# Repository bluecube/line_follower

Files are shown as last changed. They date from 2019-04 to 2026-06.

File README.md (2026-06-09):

Line follower v2
================

This is a robot I made to tinker with and to compete in the [Robotic Day](https://roboticday.org/) competition. (Actually the original goal was Robotic Day 2016, but stuff got delayed :) )

The design is an attempt to make a line follower with minimum effort on the hardware side and maximum versatility on the software side.

The robot body consists of a 8cm x 10cm double sided PCB, two geared N20 DC encoder motors with Pololu wheels and magnetic encoders and a few 3D printed bits.
The most important electronic components are ESP32 development board for computing power and line sensor inspired by [Ondřej Staněk's PocketBot](http://www.ostan.cz/pocketBot/), as a bonus the robot also carries an IR range sensor and MPU 6050 breakout board (accelerometer and gyro).

This repository should contain everything necessary to build and run the robot in the competition.
Let me know if you decide to build it!

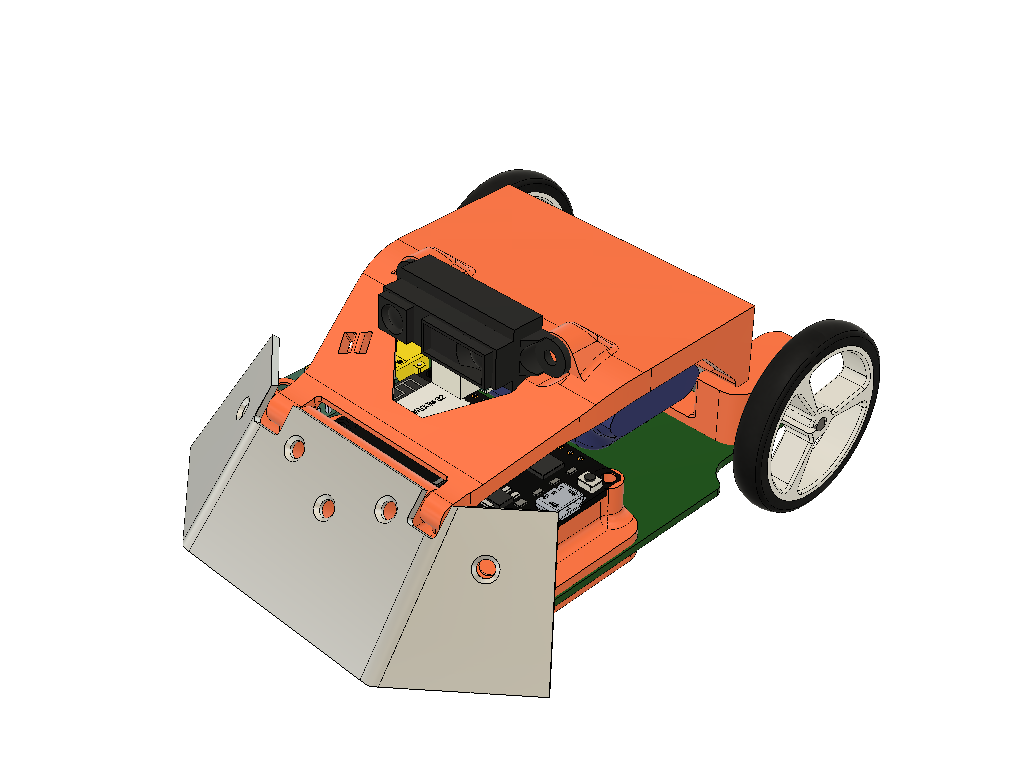
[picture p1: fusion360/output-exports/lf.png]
Render of the robot


This is a v2, you can also check out the [v1](https://github.com/bluecube/line_follower/tree/v1/).

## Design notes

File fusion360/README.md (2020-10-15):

The robot has a PCB base with 3D printed parts bolted to it.

All 3D printed parts should be printable without supports, although
some parts are a little more difficult:

- Deck is printed standing on the (only) flat face. It is tall and overhanging, good cooling is necesary. Orient the longer side of the base along the movement of the Y axis.
- Motor bracket has long bridges supported only by thin columns.

The mechanical design was done in a little roundabout way:

1. 2D sketches of the PCB were done in F360 (`board-base-sketches.f3d`)
2. The base sketches were exported to DXF files in the `pcb-exports/` directory.
3. PCB was designed based on these exported DXF files (`../kicad/`)
4. The PCB design was then exported as STEP, imported into F360 and used as a base for most of the 3D modelling (`lf.f3z`).
5. Various outputs were then exported from F360 for fabrication (`output-exports/`)

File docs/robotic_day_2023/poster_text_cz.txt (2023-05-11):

LF2
- Cíl: jednoduchý hardware, maximální flexibilita
- Ve vývoji již několik let, poprvé se blíží dokončení
- Předchozí robot Procrastinator 9000
   - Kvalifikoval se, ale nezávodil na Robotickém Dni 2019
   - Efekt druhého systému je skutečný!

Mechanika
- Základ je deska plošných spojů
- 3D tištěné díly z PETG
- Otevírací horní poklop slouží zároveň jako tlačítko zastavení
- Hliníkový pluh, spíše jen pro dekoraci
- Motory N20 s převodovkami a enkodéry
- 40mm kolečka

Elektronika a senzory
- ESP32
- Vlastní čárový senzor
   - Střídavě červené LED a fototranzistory, 10 měřených bodů
- A4950 H-můstky
- MPU6050 šestiosé IMU
- Laserový snímač vzdálenosti

Software
- PlatformIO pro správu toolchainu a závislostí
- C++17
- Používá ESP-IDF, ne Arduino
- Vrstva abstrakce hardwaru
   - Skryje přístup k ESP-IDF, hardware robota reprezentovaný jako singleton třída
- Hierarchický stavový automat pro programování chování

3D modely, elektronika, kód a dokumentace jsou k dispozici na https://github.com/bluecube/line_follower

Zeptejte se mě více o projektu: blue.cube@seznam.cz

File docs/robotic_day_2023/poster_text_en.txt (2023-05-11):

LF2
- Design goal: simple hardware, maximum flexibility
- In development for several years now, first time close to being finished
- Preceeded by Procrastinator 9000
  - Qualified, but didn't race in Robotic Day 2019
  - Second system effect is real!

Mechanical
- PCB base
- 3D printed PETG parts
- Opening top hatch doubles as a stop button
- Alluminium armor/plow, mostly decorative
- N20 gear motors with encoders
- 40mm wheels

Electronics and sensors
- ESP32
- Custom line sensor
  - Alternating red LEDs and phototransistors, 10 measured points
- A4950 H-bridges
- MPU6050 six axis IMU
- Laser distance sensor

Software
- PlatformIO for toolchain and dependency management
- C++17
- Using ESP-IDF, not Arduino
- Hardware abstraction layer
  - Hides ESP-IDF access, robot hardware represented as a singleton class
- Hierarchical state machine for programming behaviors

3D and electronics design, code and documentation are available at https://github.com/bluecube/line_follower

Ask me more about the project: blue.cube@seznam.cz

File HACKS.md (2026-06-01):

# HACKS.md

Known workarounds for hardware and driver issues.

## esp-hal `Adc::new` ignores attenuation for ADC2

`Adc::new` hardcodes `ADC1::set_attenuation` even when called with an `ADC2` peripheral, so ADC2
channels are silently left at the register default instead of the requested attenuation.

Workaround in `lf-hal/src/line_sensor.rs`: after both `Adc` instances drop, manually call
`ADC2::set_attenuation` for every ADC2 channel.

TODO: We have since upgraded esp-hal, maybe it's not necessary any more.

## BLE PHY ISR corrupts ADC2 reads

The BLE stack uses ADC2 for TX power detection. After each measurement the PHY ISR leaves
`SAR2_PWDET_FORCE=1` in `SAR_READ_CTRL2`, routing the ADC2 input mux to the internal PWDET
signal instead of the GPIO pin. Reading ADC2 without clearing this bit returns garbage.

Workaround in `lf-hal/src/line_sensor.rs`: `start_adc2()` clears `sar2_pwdet_force` before every
conversion, and every ADC2 read is wrapped in a `critical_section` to prevent the PHY ISR from
re-setting the bit between the clear and the read.

Note: the next hardware revision should route all phototransistor ADC lines to ADC1, eliminating
both workarounds.

## GPIO 12 strapping pin conflict with distance sensor

The IR distance sensor is connected to GPIO 12, which is the MTDI strapping pin on the ESP32. At
boot, the ESP32 samples this pin to determine the VDD_SDIO regulator voltage: HIGH selects 1.8V,
LOW selects 3.3V. With the sensor connected the pin was driven HIGH, causing the chip to boot with
VDD_SDIO at 1.8V and preventing correct operation and flashing.

Fix: permanently burned the VDD_SDIO efuse to force 3.3V, disabling GPIO 12's role as a strapping
pin. This is irreversible. Command used (via PlatformIO's bundled esptool):

```
pip install ecdsa reedsolo bitstring
pio pkg exec --package "platformio/tool-esptoolpy" -- espefuse.py --port /dev/ttyUSB1 set_flash_voltage 3.3V
```

See also: `docs/instructions.md`.

## Button noise

Deck button seems to have problems with EMI when mtors are spinning at full.
So far this only appears in motor_test.rs.
Either we will require multiple samples from the button to agree, or an electrical solution
(caps on the motors, caps on the button). Perhaps both.

TODO: Verify and implement the fixes

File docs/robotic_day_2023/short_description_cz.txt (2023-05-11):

LF2 je robot navržený s důrazem na jednoduchou hardwarovou konstrukci a co největší flexibilitu.
Jeho vývoj probíhá již několik let, přičemž největší pokrok obvykle dosahuje
noc před (většinou neůspěšnou) registrací na Robotický Den.
Robotovi LF2 předcházel robot Procrastinator 9000 navržený s podobným přístupem.
(Nejen) kvůli tomu trpí LF2 silným efektem druhého systému ("nevadí že to bude mohem víc práce, radši to udělám P O Ř Á D N Ě").

Základem konstrukce je deska plošných spojů, na kterou jsou přišroubované díly 3D tištěné z PETG a hliníková radlice (spíš designový než funkční prvek).
Pohyb robota zajišťují dva motory N20 s převodovkou a kvadraturním enkodérem a 40mm Pololu kolečka.
Pro sledování čáry robot používá snímač složený ze šesti červených LED a pěti
fototranzistorů, dohromady tak umožňuje měřit odrazivost podložky na deseti pozicích (mezi dvojicemi LED a fototranzistorů).
Modul s ESP32 poskytuje naprosto nadbytečné množství výpočetního výkonu a v rezervě je ještě šestiosé IMU MPU6050 a laserový senzorem vzdálenosti.

Software robota je napsaný v jazyce C++17 a pro přístup k periferiím využívá knihovnu ESP-IDF (žádné Arduino!).
Software definuje vrstvu pro abstrakci hardwaru (HAL), která obaluje všechny přístupy k ESP-IDF, čísla pinů a podobné do jedné třídy pro snazší testování a případnou simulaci.
Chování robota při soutěži řídí jedoduchý stavový automat.
Pro správu překladače, závislostí a dalších součástí je použito prostředí Platformio (https://platformio.org).

Veškeré 3D modely, kód a dokumentace k robotu LF2 je k dispozici na GitHubu na adrese https://github.com/bluecube/line_follower.

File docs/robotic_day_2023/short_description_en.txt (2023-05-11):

LF2 is a robot designed with an emphasis on simple hardware construction and maximum flexibility.
Its development has been going on for several years, and it usually makes the most progress
the night before the (usually unsuccessful) registration for Robotic Day.
The LF2 robot was preceded by the Procrastinator 9000 robot designed with a similar approach.
(Not only) because of this, LF2 suffers from a strong second system effect ("it doesn't matter that it will be more work for me, I'd rather do it P R O P E R L Y").

The basis of the structure is a printed circuit board, on which parts 3D printed out of PETG and an aluminum armor/plow blade (more of a design element than a functional element) are screwed.
The movement of the robot is taken care of by two N20 gear motors with quadrature encoders and 40mm Pololu wheels.
To track the line, the robot uses a sensor composed of six red LEDs and five phototransistors, together this allows measuring the reflectivity of the surface at ten positions (between pairs of LEDs and phototransistors).
The module with ESP32 provides a completely unnecessary amount of computing power and there is a six axis IMU MPU6050 and a laser distance sensor in reserve.

The robot software is written using C++17 and uses the ESP-IDF library to access peripherals (no Arduino!).
The software defines a hardware abstraction layer (HAL) that wraps all ESP-IDF accesses, pin numbers, and the like into a single class for easier testing and eventual simulation.
The behavior of the robot during the competition is controlled by a simple state machine.
Platformio environment (https://platformio.org) is used to manage the compiler, dependencies and other components.

All 3D models, code and documentation for the LF2 bot is available on GitHub at https://github.com/bluecube/line_follower.

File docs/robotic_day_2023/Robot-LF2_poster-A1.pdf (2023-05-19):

# ROBOT LF2

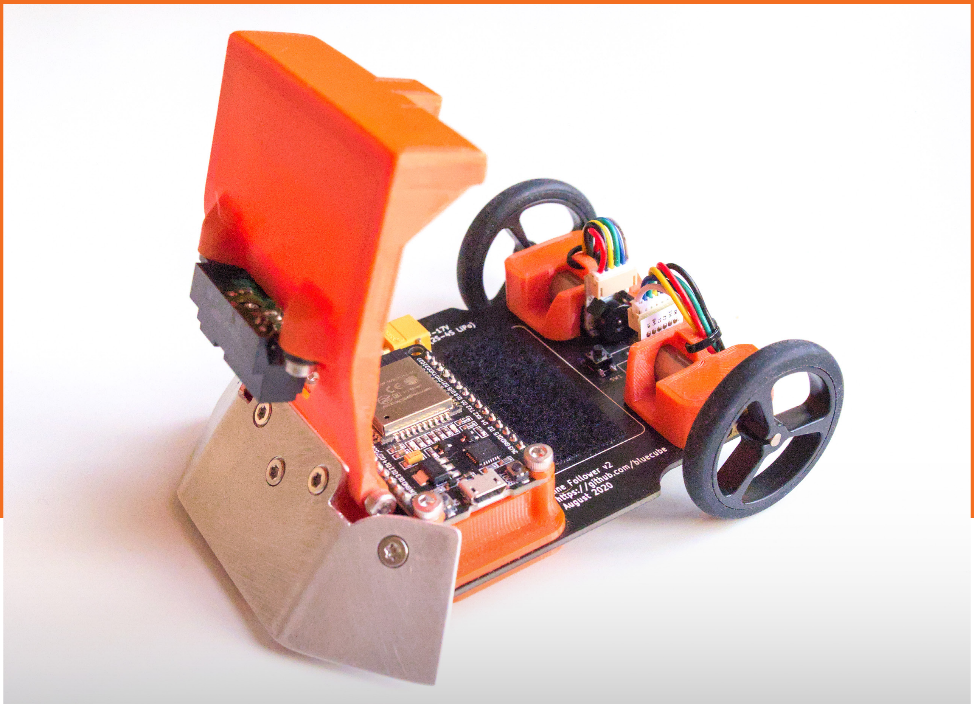
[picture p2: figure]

Mechanical
□ PCB base
□ 3D printed PETG parts
□ Opening top hatch doubles as a stop button □ Alluminium armor/plow, mostly decorative □ N20 gear motors with encoders
□ 40mm wheels
Electronics and sensors
□ ESP32
□ Custom line sensor
□ Alternating red LEDs and phototransistors, 10 measured points
□ A4950 H-bridges
□ MPU6050 six axis IMU
□ Laser distance sensor
Software
□ PlatformIO for toolchain and dependency management
□ C++17
□ Using ESP-IDF, not Arduino
□ Hardware abstraction layer
□ Hides ESP-IDF access, robot hardware represented as a singleton class
□ Hierarchical state machine for programming behaviors

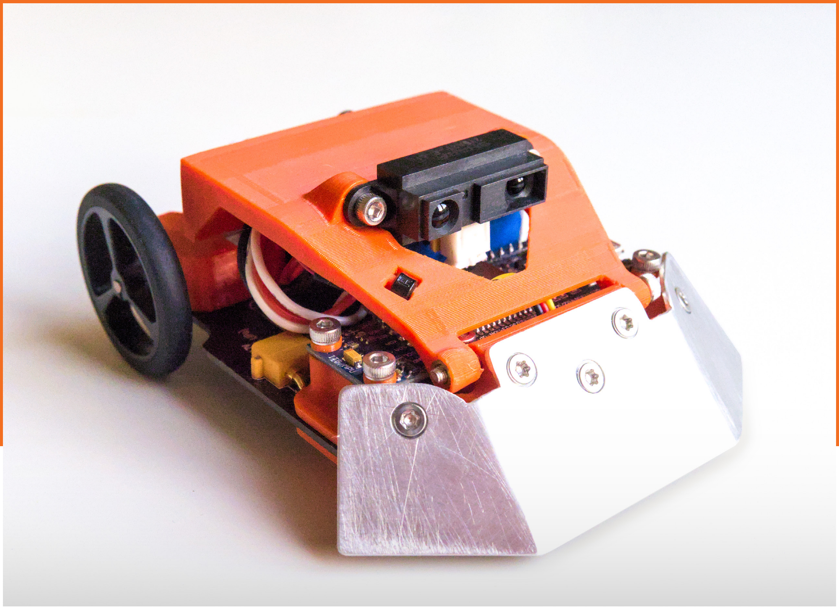
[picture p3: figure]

Mechanika
□ Základ je deska plošných spojů
□ 3D tištěné díly z PETG
□ Horní poklop slouží zároveň jako stop tlačítko □ Hliníkový pluh, spíše jen pro dekoraci
□ Motory N20 s převodovkami a enkodéry
□ 40mm kolečka
Elektronika a senzory
□ ESP32
□ Vlastní čárový senzor
□ Střídavě červené LED a fototranzistory, 10 měřených bodů
□ A4950 H-můstky
□ MPU6050 šestiosé IMU
□ Laserový snímač vzdálenosti
Software
□ PlatformIO pro správu toolchainu a závislostí □ C++17
□ Používá ESP-IDF, ne Arduino
□ Vrstva abstrakce hardwaru
□ Skryje přístup k ESP-IDF, hardware robota reprezentovaný jako singleton třída
□ Hierarchický stavový automat pro programování chování

## CÍL: jednoduchý hardware, maximální flexibilita DESIGN GOALS: simple hardware, maximum flexibility

## In development for many years now, first time close to being finished. It was preceeded by robot Procrastinator 9000, which Qualified, but didn’t race in Robotic Day 2019. Second system effect is real!

## Ve vývoji již několik let, poprvé se blíží dokončení. Předchozí robot

Procrastinator 9000 se kvalifikoval, ale nezávodil na Robotickém Dni 2019.

## Efekt druhého systému je skutečný!

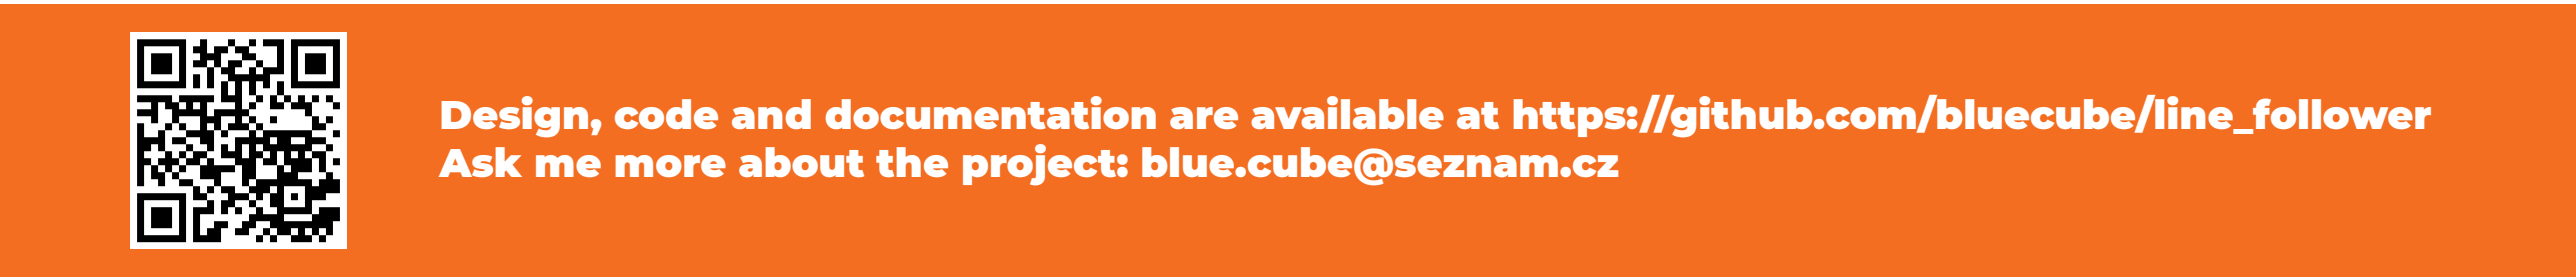
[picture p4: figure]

Design, code and documentation are available at https://github.com/bluecube/line_follower Ask me more about the project: blue.cube@seznam.cz

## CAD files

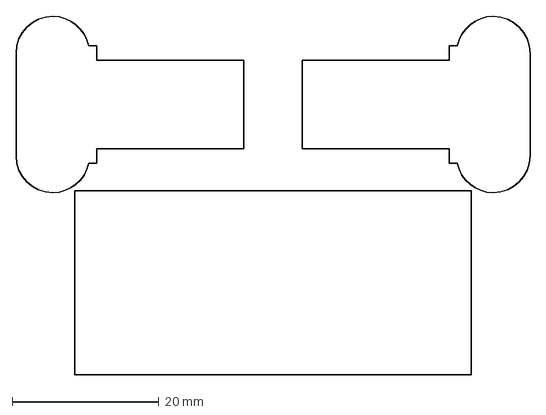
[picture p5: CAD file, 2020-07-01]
fusion360/dxf-exports/top-blockers-kicad-export.dxf
70.0 x 48.8 mm

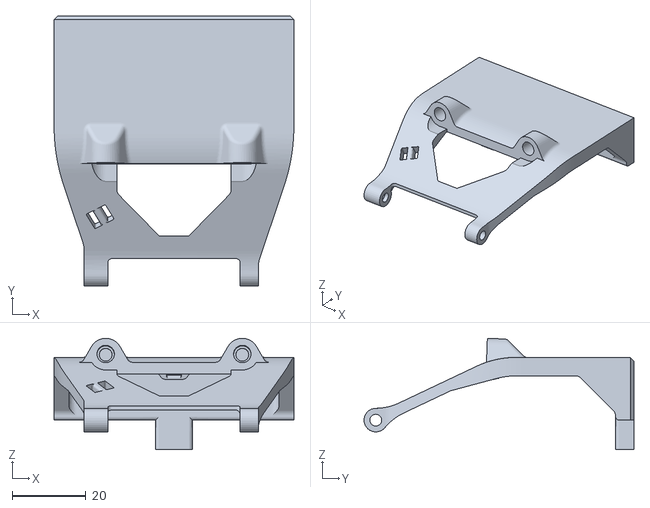
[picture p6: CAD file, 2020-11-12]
fusion360/output-exports/fdm-deck.stl
65.0 x 73.2 x 30.2

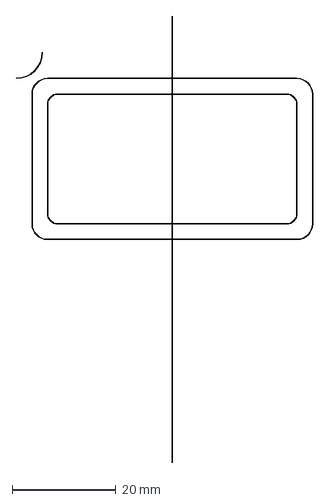
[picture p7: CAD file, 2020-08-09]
fusion360/pcb-exports/battery-outline.dxf
57.0 x 86.0 mm

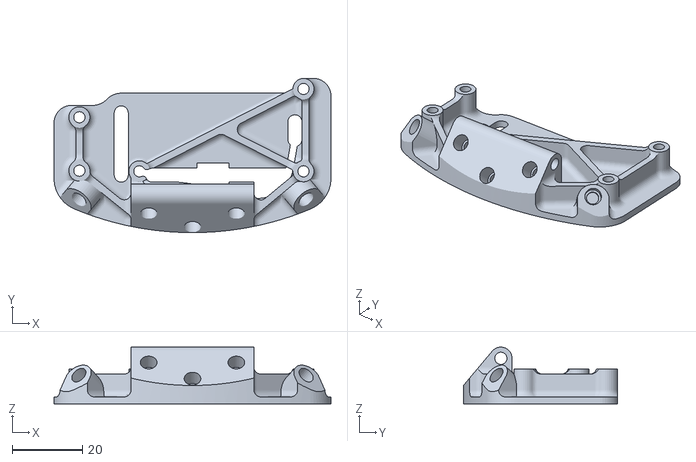
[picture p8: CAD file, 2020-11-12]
fusion360/output-exports/fdm-front_top.stl
79.0 x 44.0 x 16.2

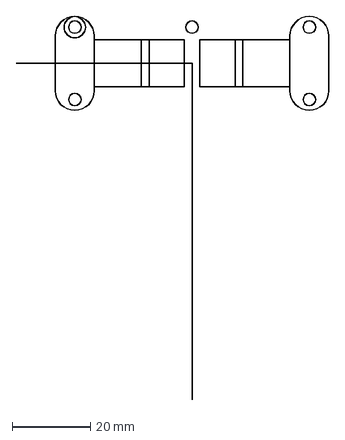
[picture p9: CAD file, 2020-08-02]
fusion360/pcb-exports/motor_mounts_outline.dxf
80.0 x 98.0 mm

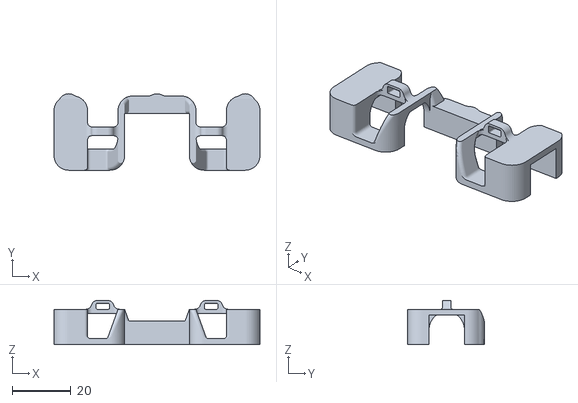
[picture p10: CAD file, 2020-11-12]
fusion360/output-exports/fdm-motor_bracket.stl
70.0 x 26.0 x 15.0

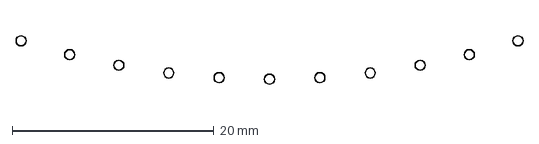
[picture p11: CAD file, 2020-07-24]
fusion360/pcb-exports/line-sensor-components.dxf
50.3 x 4.80 mm

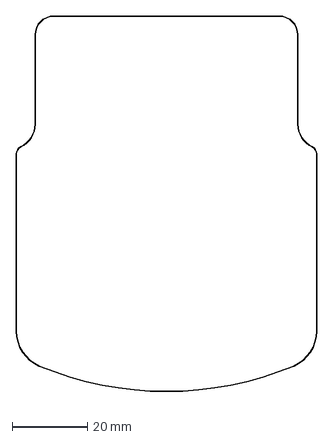
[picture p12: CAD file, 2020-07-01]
fusion360/pcb-exports/board-outline.dxf
80.0 x 102.3 mm

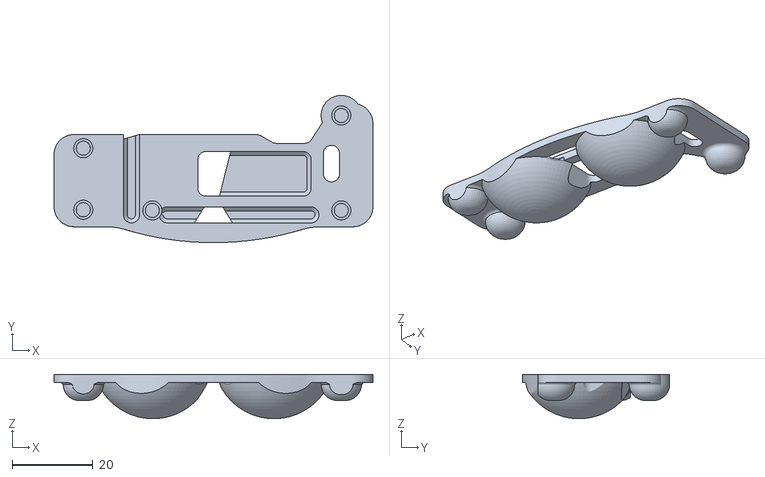
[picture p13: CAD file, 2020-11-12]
fusion360/output-exports/fdm-front_bottom.stl
79.0 x 36.5 x 11.0

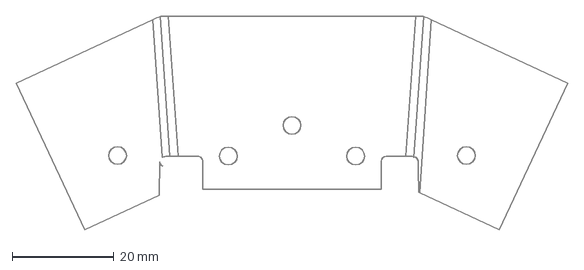
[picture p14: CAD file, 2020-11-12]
fusion360/output-exports/armor.dxf
108.1 x 42.0 mm

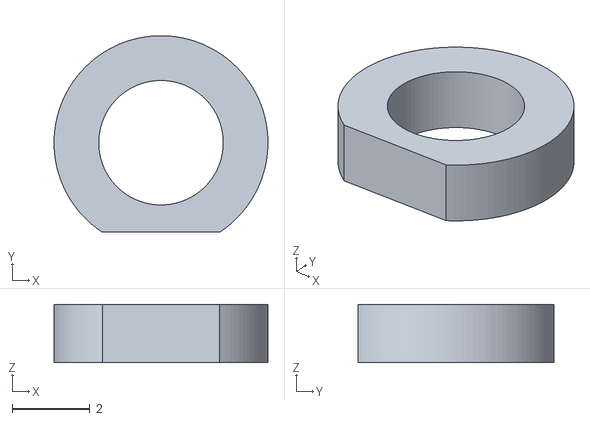
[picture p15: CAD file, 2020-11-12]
fusion360/output-exports/fdm-cut_washer.stl
5.50 x 5.05 x 1.50

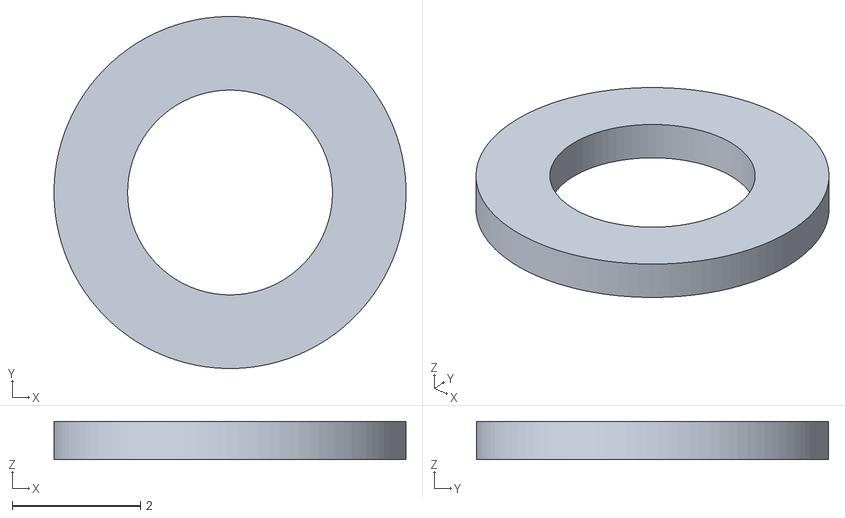
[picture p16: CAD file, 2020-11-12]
fusion360/output-exports/fdm-flat_washer.stl
5.50 x 5.50 x 0.6

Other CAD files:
solidworks/testing_map.sldprt
fusion360/board-base-sketches.f3d
fusion360/lf.f3z
fusion360/off_the_shelf/microswitch_4.5mm.f3d

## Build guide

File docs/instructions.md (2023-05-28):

# Getting the robot to work

This is mostly a random collection of things.
Not complete by any means.

## Install platformio
I couldn't get platformio to work normally, so instead I used a virtual environment:

```
python -m venv venv
. venv/bin/activate
pip install platformio
```

Then I can do
```
platformio run
```

The top level Makefile already assumes that the venv is used.

# Fixing GPIO12 conflicting with the distance sensor

By default, the board cannot be flashed correctly when the distance sensor is connected, because GPIO12 is a strapping pin (MTDI).
I followed instructions in [ESP32 docs](https://docs.espressif.com/projects/esptool/en/latest/esp32/espefuse/set-flash-voltage-cmd.html) and permantently set the VDD_SDIO regulator to 3.3V.
This disables the use of GPIO12 as a strapping pin, but it's an irreversible change.

Platformio doesn't let me directly use the `espfuse.py`, has to be accessed through a package.
In addition, there are some dependencies missing, so I installed them in the virtual env.
I also had to specify port for connecting to the ESP32.

Final commands:
```
pip install ecdsa reedsolo bitstring
pio pkg exec --package "platformio/tool-esptoolpy" -- espefuse.py --port /dev/ttyUSB1 set_flash_voltage 3.3V
```

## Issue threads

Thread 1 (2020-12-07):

GPIO12 (distance sensor) breaks flashing

bluecube, 2020-12-07:
The board cannot be flashed correctly when the distance sensor is connected, because GPIO12 is a strapping pin (MTDI).

bluecube, 2020-12-25:
Maybe swap it with SDA or SCL?

bluecube, 2023-03-03:
https://docs.espressif.com/projects/esptool/en/latest/esp32/espefuse/set-flash-voltage-cmd.html

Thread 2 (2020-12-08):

Line sensor LEDs 5 and 6 should be switched to simplify charlieplex encoding in software

bluecube, 2020-12-08:

bluecube, 2020-12-11:
... or not. The current state is simple enough, even though it is not as nice and regular as it could be

Closed 2020-12-11.

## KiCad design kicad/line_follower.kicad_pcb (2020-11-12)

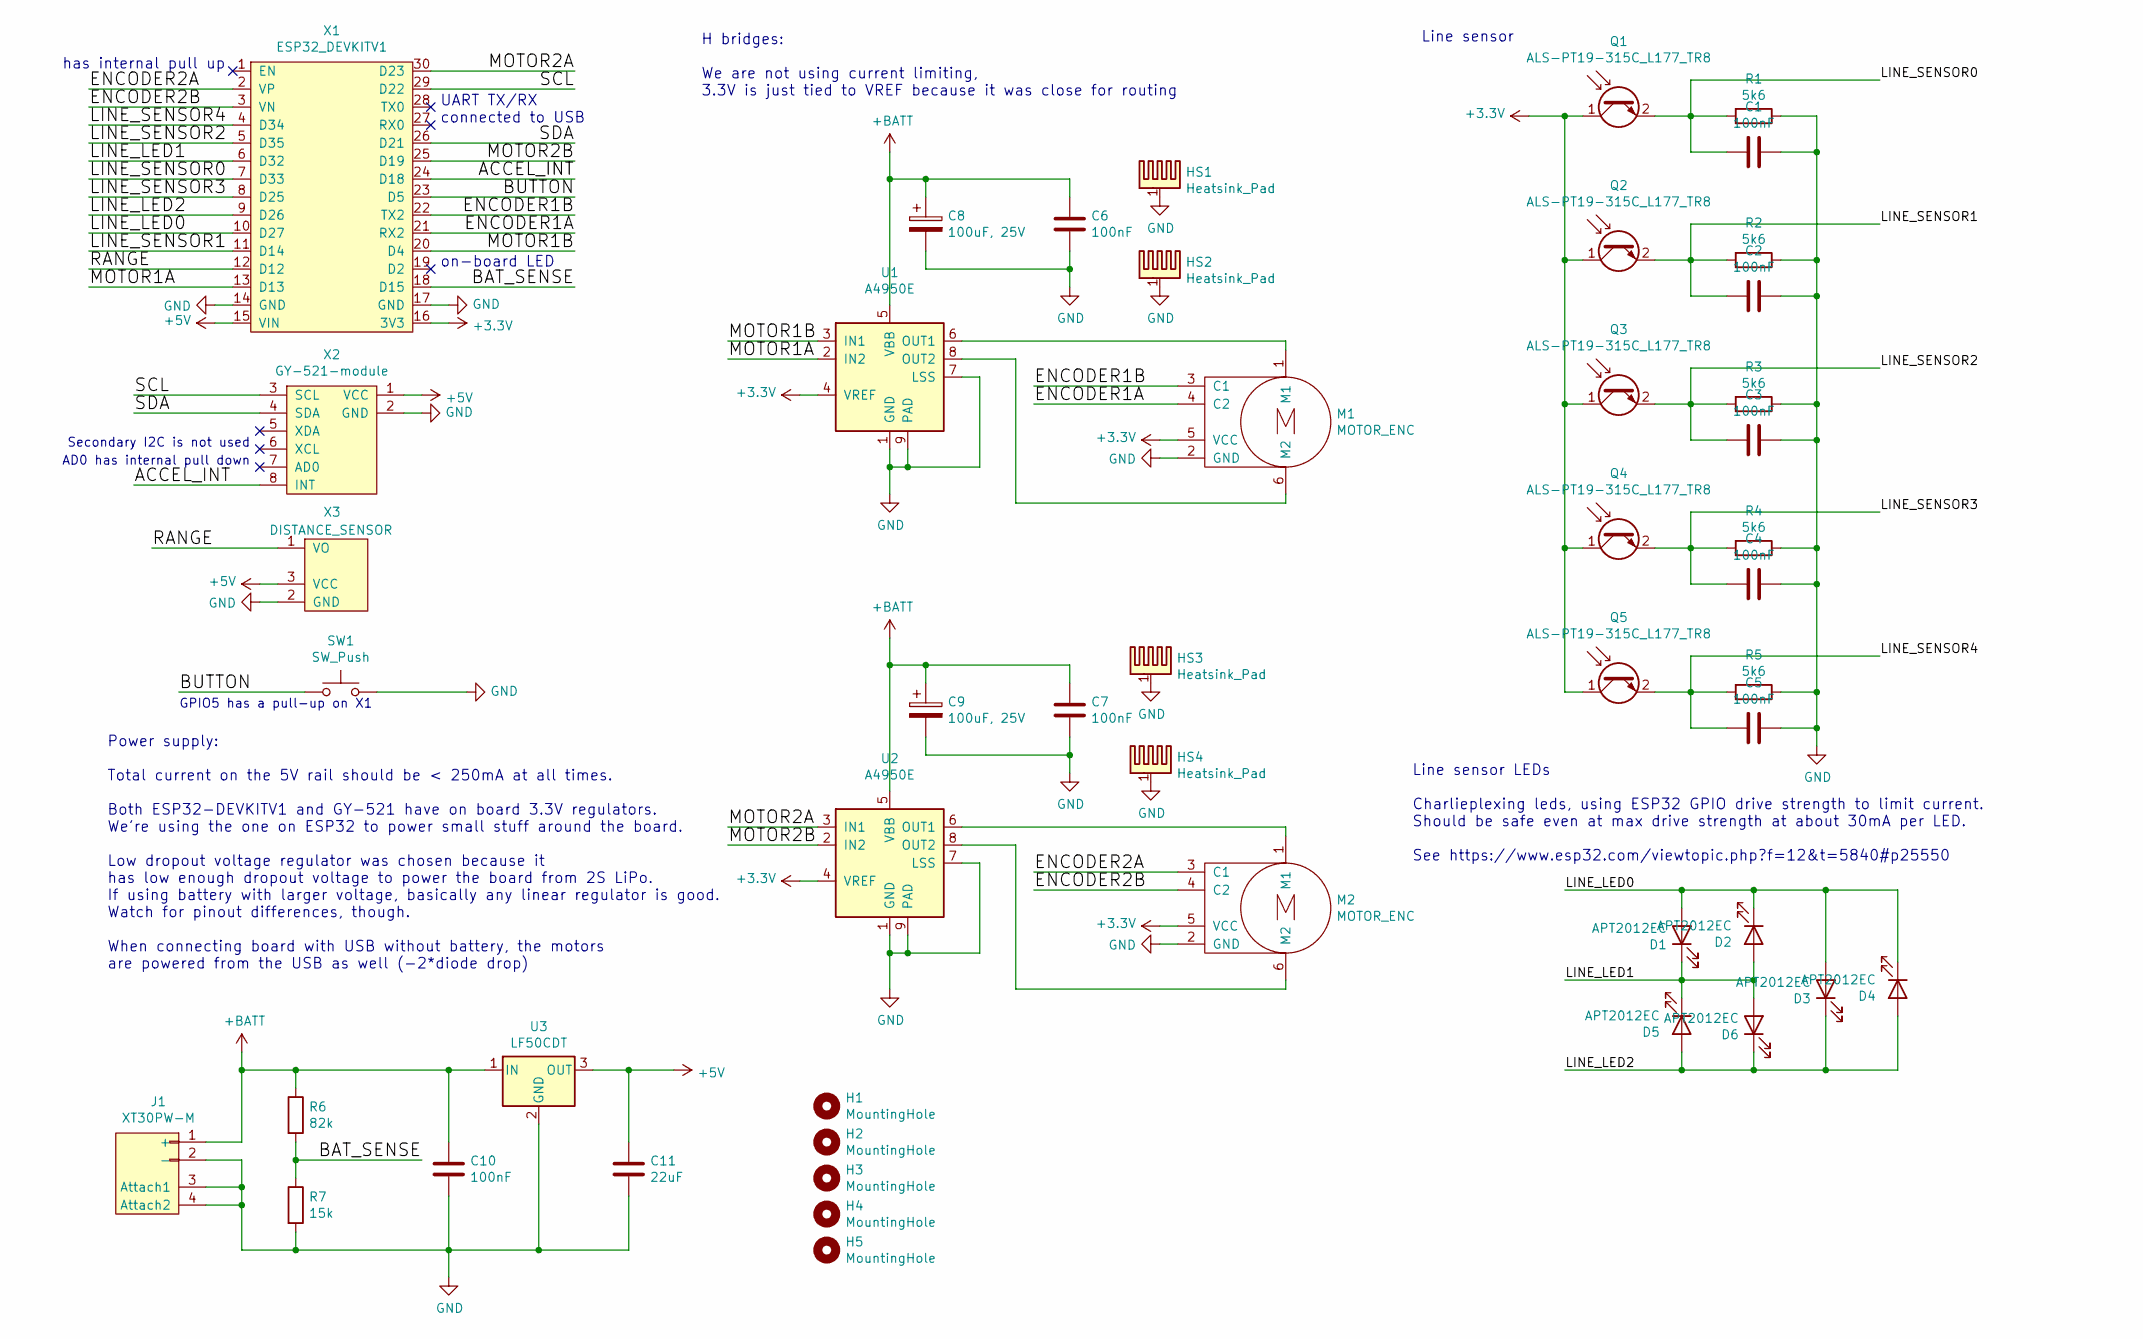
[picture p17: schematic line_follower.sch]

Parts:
C1, C2, C3, C4, C5, C6, C7, C10: 100nF; C_0805_2012Metric_Pad1.15x1.40mm_HandSolder
C8, C9: 100uF, 25V; CP_Elec_6.3x5.8
C11: 22uF; C_0805_2012Metric_Pad1.15x1.40mm_HandSolder
D1, D2, D3, D4, D5, D6: APT2012EC; LED_0805_2012Metric_Pad1.15x1.40mm_HandSolder
H1, H2, H3, H4, H5: MountingHole; MountingHole_3.2mm_M3
HS1, HS2, HS3, HS4: Heatsink_Pad; 3x3_thermal_vias
J1: XT30PW-M
M1, M2: MOTOR_ENC; SolderWirePad2x3_p2.54_staggered
Q1, Q2, Q3, Q4, Q5: ALS-PT19-315C_L177_TR8; phototransistor-1.7mm
R1, R2, R3, R4, R5: 5k6; R_0805_2012Metric_Pad1.15x1.40mm_HandSolder
R6: 82k; R_0805_2012Metric_Pad1.15x1.40mm_HandSolder
R7: 15k; R_0805_2012Metric_Pad1.15x1.40mm_HandSolder
SW1: SW_Push; 4.5mm_tact_switch
U1, U2: A4950E; SOIC-8-1EP_3.9x4.9mm_P1.27mm_EP2.41x3.3mm_HandSolder
U3: LF50CDT; TO-252-2
X1: ESP32_DEVKITV1
X2: GY-521-module
X3: DISTANCE_SENSOR; SolderWirePad1x3_p2.54

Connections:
+3V3: M1.5 (VCC), M2.5 (VCC), Q1.1 (C), Q2.1 (C), Q3.1 (C), Q4.1 (C), Q5.1 (C), U1.4 (VREF), U2.4 (VREF), X1.16 (3V3)
+5V: C11.1, U3.3 (OUT), X1.15 (VIN), X2.1 (VCC), X3.3 (VCC)
+BATT: C6.1, C7.1, C8.1, C9.1, C10.1, J1.1 (+), R6.1, U1.5 (VBB), U2.5 (VBB), U3.1 (IN)
/ACCEL_INT: X1.24 (D18), X2.8 (INT)
/BAT_SENSE: R6.2, R7.1, X1.18 (D15)
/BUTTON: SW1.1, X1.23 (D5)
/ENCODER1A: M1.4 (C2), X1.21 (RX2)
/ENCODER1B: M1.3 (C1), X1.22 (TX2)
/ENCODER2A: M2.3 (C1), X1.2 (VP)
/ENCODER2B: M2.4 (C2), X1.3 (VN)
/LINE_LED0: D1.2 (A), D2.1 (K), D3.2 (A), D4.1 (K), X1.10 (D27)
/LINE_LED1: D1.1 (K), D2.2 (A), D5.1 (K), D6.2 (A), X1.6 (D32)
/LINE_LED2: D3.1 (K), D4.2 (A), D5.2 (A), D6.1 (K), X1.9 (D26)
/LINE_SENSOR0: C1.2, Q1.2 (E), R1.2, X1.7 (D33)
/LINE_SENSOR1: C2.2, Q2.2 (E), R2.2, X1.11 (D14)
/LINE_SENSOR2: C3.2, Q3.2 (E), R3.2, X1.5 (D35)
/LINE_SENSOR3: C4.2, Q4.2 (E), R4.2, X1.8 (D25)
/LINE_SENSOR4: C5.2, Q5.2 (E), R5.2, X1.4 (D34)
/MOTOR1A: U1.2 (IN2), X1.13 (D13)
/MOTOR1B: U1.3 (IN1), X1.20 (D4)
/MOTOR2A: U2.3 (IN1), X1.30 (D23)
/MOTOR2B: U2.2 (IN2), X1.25 (D19)
/RANGE: X1.12 (D12), X3.1 (VO)
/SCL: X1.29 (D22), X2.3 (SCL)
/SDA: X1.26 (D21), X2.4 (SDA)
GND: C1.1, C2.1, C3.1, C4.1, C5.1, C6.2, C7.2, C8.2, C9.2, C10.2, C11.2, HS1.1, HS2.1, HS3.1, HS4.1, J1.2 (-), J1.3 (Attach1), J1.4 (Attach2), M1.2 (GND), M2.2 (GND), R1.1, R2.1, R3.1, R4.1, R5.1, R7.2, SW1.2, U1.1 (GND), U1.7 (LSS), U1.9 (PAD), U2.1 (GND), U2.7 (LSS), U2.9 (PAD), U3.2 (GND), X1.14 (GND), X1.17 (GND), X2.2 (GND), X3.2 (GND)
unnamed: M1.1 (M1), U1.6 (OUT1)
unnamed: M1.6 (M2), U1.8 (OUT2)
unnamed: M2.1 (M1), U2.6 (OUT1)
unnamed: M2.6 (M2), U2.8 (OUT2)

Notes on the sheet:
Power supply: Total current on the 5V rail should be < 250mA at all times. Both ESP32-DEVKITV1 and GY-521 have on board 3.3V regulators. We're using the one on ESP32 to power small stuff around the board. Low dropout voltage regulator was chosen because it has low enough dropout voltage to power th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
UART TX/RX connected to USB
on-board LED
AD0 has internal pull down
has internal pull up
Secondary I2C is not used
H bridges: We are not using current limiting, 3.3V is just tied to VREF because it was close for routing
Line sensor LEDs Charlieplexing leds, using ESP32 GPIO drive strength to limit current. Should be safe even at max drive strength at about 30mA per LED. See https://www.esp32.com/viewtopic.php?f=12&t=5840#p25550
Line sensor
GPIO5 has a pull-up on X1

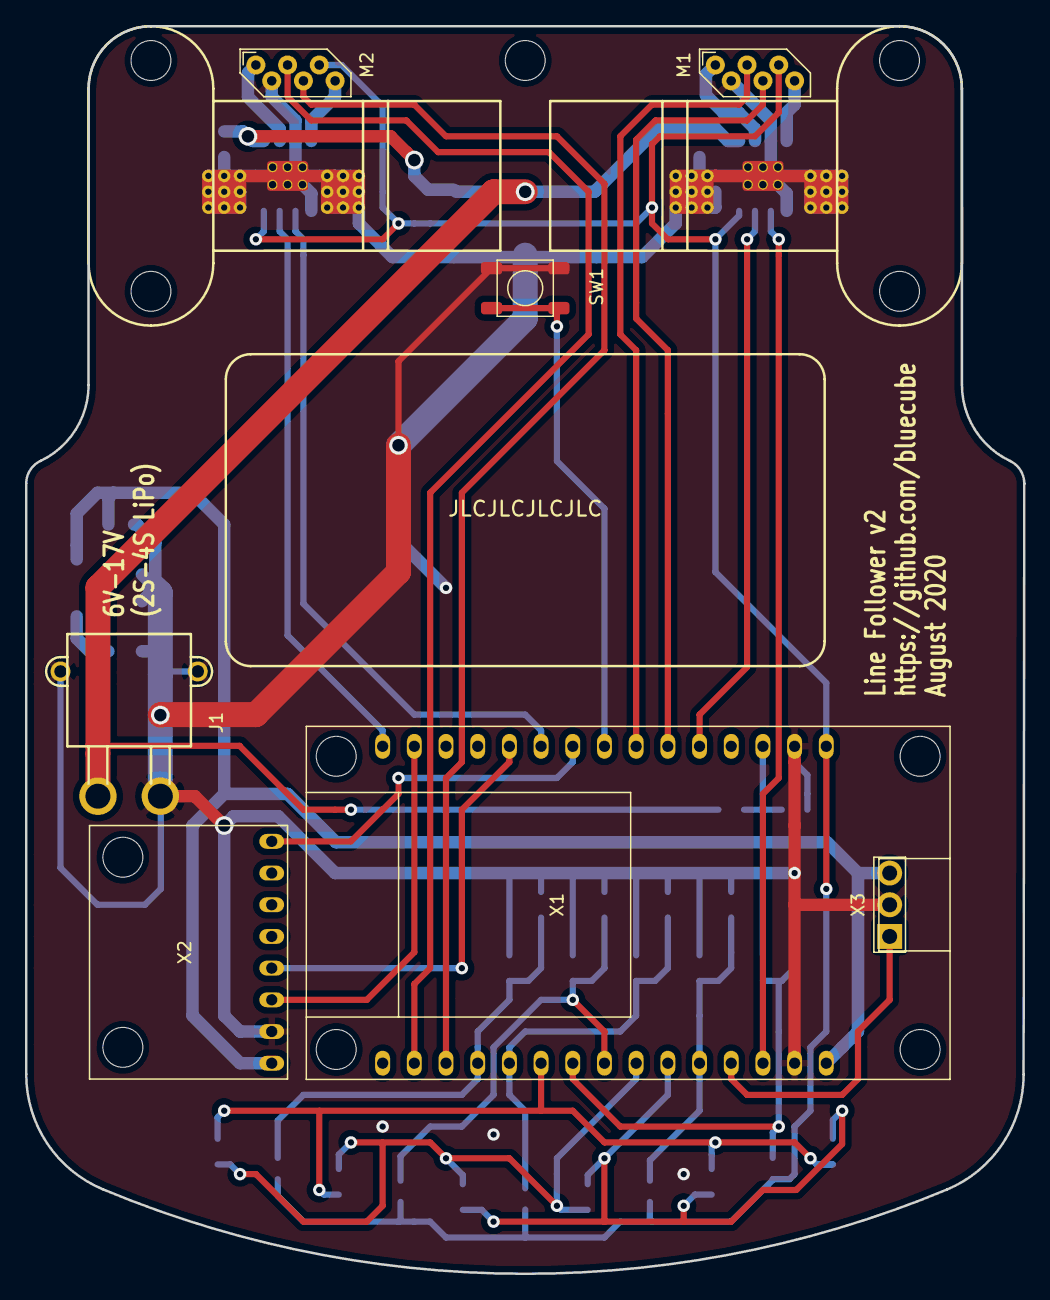
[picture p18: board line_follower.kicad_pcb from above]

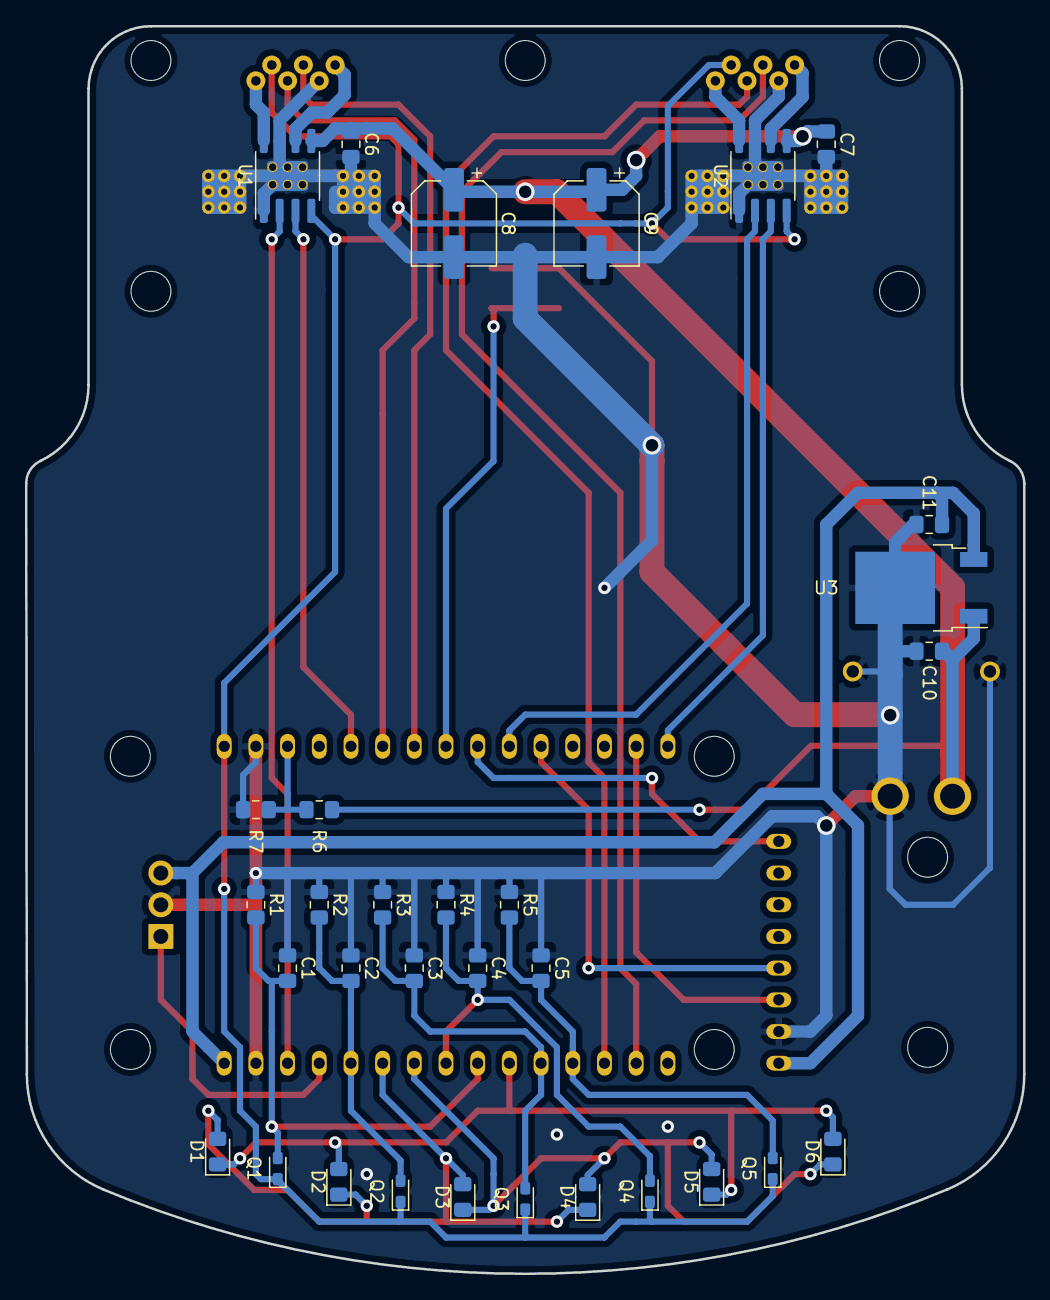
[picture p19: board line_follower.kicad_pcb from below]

Board: 2 copper layers, 80.0 x 100.0 mm, 48 parts (32 on the bottom side), 30 nets.

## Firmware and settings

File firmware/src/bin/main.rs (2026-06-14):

#![no_std]
#![no_main]
#![deny(
    clippy::mem_forget,
    reason = "mem::forget is generally not safe to do with esp_hal types, especially those \
    holding buffers for the duration of a data transfer."
)]

extern crate alloc;

use embassy_executor::Spawner;
use embassy_futures::select::{Either, select};
use embassy_time::{Duration, Instant, Ticker};
use esp_backtrace as _;
use fixed::types::I9F23;
use itertools::Itertools as _;
use lf_hal::{
    Hal, RangeSensor,
    button::ButtonEvent,
    line_sensor::{LedIndex, LineSensor},
    motors::Motors,
};
use lf_hal_types::{
    RangeMeasurement,
    motors::{MAX_SPEED, METERS_PER_TICK, PwmT},
};
use line_follower::{
    line_detection::{LineDetection, PositionT, detect_line},
    velocity_controller::{Gain, Gains, VelocityController},
};

esp_bootloader_esp_idf::esp_app_desc!();

const BASE_SPEED: i32 = 1000;
const STEERING_DERIV_LENGTH_TICKS: i32 = 64; // Distance over which the steering derivative is averaged (~15 mm)
const STEERING_KP: Gain = Gain::lit("0.75");
const STEERING_LEAD_TICKS: i32 = 384; // Derivative look-ahead distance along the path. Must be multiple of STEERING_DERIV_LENGTH_TICKS.
const KP: f32 = 0.4;
const TI: f32 = 0.3;
const TD: f32 = 0.005;
const STICTION_PWM: PwmT = PwmT::new_static::<400>();
const OBSTACLE_STOP_M: f32 = 0.15;
const OBSTACLE_CLEAR_M: f32 = 0.30;
const OBSTACLE_CLEAR_DURATION: Duration = Duration::from_secs(3);
const LOST_LINE_DIST_TICKS: i32 = (0.3 / METERS_PER_TICK) as i32;
const MAIN_LOOP_PERIOD: Duration = Duration::from_millis(10);
const OBSTACLE_POLL: Duration = Duration::from_millis(100);
const LINE_CENTERED_THRESHOLD: PositionT = PositionT::lit("0.5");
const SCAN_INTERVAL: Duration = Duration::from_millis(120);

type Position32T = fixed::types::I6F26;

#[esp_rtos::main]
async fn main(spawner: Spawner) {
    let mut hal = line_follower::init!(spawner);
    loop {
        wait_for_start(&mut hal).await;

        if let Either::Second(()) = select(
            follow_line(&mut hal.motors, &mut hal.line_sensor, &hal.range),
            hal.deck_button.pressed(),
        )
        .await
        {
            hal.motors.stop();
            log::info!("Stopped by button.");
        }
    }
}

async fn wait_for_start(hal: &mut Hal<'_>) {
    const LED_ANIMATION: [usize; 10] = [0, 1, 2, 3, 4, 5, 4, 3, 2, 1];
    const STARTING_LINE_DETECTION_COUNT_THRESHOLD: usize = 3;
    log::info!("Waiting: center line on sensor, then press deck button");
    let mut ticker = Ticker::every(SCAN_INTERVAL);
    hal.line_sensor.disable_leds();

    loop {
        let mut animation_index: usize = 0;
        let mut line_detected_count = 0;
        loop {
            if let Some(d) = read_line_for_start(hal).await {
                line_detected_count += 1;

                if line_detected_count >= STARTING_LINE_DETECTION_COUNT_THRESHOLD {
                    log::info!(
                        "Line centered (pos {}, strength {}), press deck button to start",
                        d.position,
                        d.strength
                    );
                    break;
                }
            } else {
                line_detected_count = 0;
            }

            let led_index = LedIndex::new(LED_ANIMATION[animation_index]).unwrap();
            animation_index = (animation_index + 1) % LED_ANIMATION.len();
            hal.line_sensor.enable_led(led_index);

            ticker.next().await;
        }

        loop {
            match select(hal.deck_button.next_event(None), ticker.next()).await {
                Either::First(ButtonEvent::Press) => {
                    hal.line_sensor.disable_leds();
                    hal.deck_button.released().await;
                    log::info!("Starting");
                    return;
                }
                Either::Second(_) => {
                    if read_line_for_start(hal).await.is_none() {
                        log::info!("Line lost, reposition");
                        break;
                    }
                }
                _ => {}
            }
        }
    }
}

async fn follow_line(
    motors: &mut Motors<'_>,
    line_sensor: &mut LineSensor<'_>,
    range: &RangeSensor,
) {
    let gains = Gains::from_standard(KP, TI, TD)
        .unwrap()
        .with_stiction(STICTION_PWM);

    // Initial values
    let initial_readings = line_sensor.read().await;
    let Some(initial_pos) = detect_line(&initial_readings)
        .iter()
        .next()
        .map(|d| d.position)
    else {
        log::error!("follow_line without line detected.");
        return;
    };
    let initial_enc = motors.encoders();
    let now = Instant::now();

    // Controllers
    let mut velocity = VelocityController::new(gains, initial_enc);
    let mut steering = SteeringController::new(motors.encoders(), initial_pos);

    // Mutable loop state
    let mut line_lost_at: Option<(i16, i16)> = None;
    let mut last_good_line_position = initial_pos;
    let mut last_t = now;
    let mut range_filter = RangeFilter::new(range.read());

    let mut ticker = Ticker::every(MAIN_LOOP_PERIOD);

    loop {
        range_filter.add(range.read());
        let dist = range_filter.filtered().distance_long();

        if dist < OBSTACLE_STOP_M {
            motors.stop();
            log::info!("Obstacle at {dist:.2} m. Waiting for clear.");
            wait_for_obstacle_clear(range, &mut range_filter).await;
            let readings = line_sensor.read().await;
            let detections = detect_line(&readings);
            if detections.is_empty() {
                log::info!("Obstacle cleared but no line detected. Stopping.");
                return;
            } else {
                log::info!("Obstacle cleared. Resuming.");
                let resume_enc = motors.encoders();
                last_t = Instant::now();
                velocity.reset(resume_enc);
                ticker.reset();
            }
        }

        let readings = line_sensor.read().await;

        let detections = detect_line(&readings);
        // When multiple lines are detected, follow the leftmost (most negative position).
        // Chosen for consistency for now; revisit if we need to handle forks or intersections.
        let detection = detections.iter().min_by_key(|d| d.position).copied();

        let enc = motors.encoders();
        let now = Instant::now();
        let dt = now - last_t;
        last_t = now;

        let steering_line_position = if let Some(detection) = detection {
            let pos = detection.position;
            last_good_line_position = pos;
            line_lost_at = None;
            pos
        } else {
            if let Some(line_lost_at) = line_lost_at {
                // We were already driving with lost line, verify that we did not drive away too far.

                let dl = enc.0.wrapping_sub(line_lost_at.0) as i32;
                let dr = enc.1.wrapping_sub(line_lost_at.1) as i32;
                let dist = (dl + dr) / 2;
                if dist.abs() > LOST_LINE_DIST_TICKS {
                    motors.stop();
                    log::info!(
                        "No line after {:.2} m, stopping.",
                        dist as f32 * METERS_PER_TICK
                    );
                    return;
                }
            } else {
                // Line lost for the first time

                if last_good_line_position.abs() > LINE_CENTERED_THRESHOLD {
                    motors.stop();
                    log::info!(
                        "Line lost in outer half (pos {}), stopping.",
                        last_good_line_position
                    );
                    return;
                } else {
                    line_lost_at = Some(enc);
                    log::info!(
                        "Line lost in inner half (pos {}), continuing on arc",
                        last_good_line_position
                    );
                }
            }

            // TODO: rules allow the line to resume anywhere within a 30 degree cone from the
            // interruption point. For now we just continue in the same arc rely on the search distance.
            last_good_line_position
        };

        let speeds = steering.update(BASE_SPEED, steering_line_position, enc);
        let (l, r) = velocity.update(enc, speeds, dt);
        motors.set(l.motor_pwm, r.motor_pwm);

        ticker.next().await;
    }
}

/// Proportional steering with a distance-based derivative look-ahead.
///
/// Holds a first-order spatial low-pass of the line position whose lag estimates the path
/// derivative `d(position)/d(distance)` without dividing by the per-loop distance.
struct SteeringController {
    /// Distance-based EWMA of the line position.
    /// This approximates the line position as it was `STEERING_DERIV_LENGTH_TICKS` ago.
    filtered_pos: Position32T,
    /// Encoder reading at the previous update, for differentiating distance travelled.
    prev_enc: (i16, i16),
}

impl SteeringController {
    fn new(enc: (i16, i16), line_position: PositionT) -> Self {
        Self {
            filtered_pos: Position32T::from_num(line_position),
            prev_enc: enc,
        }
    }

    /// Returns the `(left, right)` motor speeds for a given base `speed`, the current line
    /// `line_position`, and the current encoder reading `enc` (the distance travelled since the
    /// last update is differentiated internally).
    fn update(&mut self, speed: i32, line_position: PositionT, enc: (i16, i16)) -> (i16, i16) {
        // Distance travelled since the last update, averaged across both wheels.
        let ds = (enc.0.wrapping_sub(self.prev_enc.0) as i32
            + enc.1.wrapping_sub(self.prev_enc.1) as i32)
            / 2;
        debug_assert!(
            ds < 150,
            "Guaranteed by maximum wheel speed and >= 100Hz update rate"
        );
        debug_assert!(
            ds >= 0,
            "This steering controller only works when driving forward"
        );
        self.prev_enc = enc;

        // Widen the i16-backed position into i32, scale is unchanged.
        let line_position = Position32T::from_num(line_position);

        // Smoothing weight for the EWMA distance filter depends on distance driven
        // The formula is obtained by forcing the result of this filter to estimate exactly
        // the derivative in case the input position changes linearly.
        let alpha = I9F23::from_num(ds) / (STEERING_DERIV_LENGTH_TICKS + ds);

        // Updating the smoothing EWMA
        self.filtered_pos += (line_position - self.filtered_pos).mul_add(alpha, Position32T::ZERO);

        // Effectively we calculate
        // `derivative = (line_position - self.filtered_pos) / STEERING_DERIV_LENGTH_TICKS` (in line sensor units per encoder tick)
        // `lookahead = derivative * STEERING_LEAD_RATIO` (in line sensor units),
        // but without the rounding in the middle
        const {
            assert!(
                STEERING_LEAD_TICKS % STEERING_DERIV_LENGTH_TICKS == 0,
                "Steering lead ratio should be an exact integer for this trick"
            );
        };
        const STEERING_LEAD_RATIO: i32 = STEERING_LEAD_TICKS / STEERING_DERIV_LENGTH_TICKS;
        let lookahead = (line_position - self.filtered_pos) * STEERING_LEAD_RATIO;

        // Extrapolate a fixed look-ahead distance along the path.
        let extrapolated = line_position + lookahead;

        let factor = STEERING_KP.mul_add(extrapolated, Gain::ZERO);

        let steering = (factor * speed).to_num::<i32>();
        log::debug!("{steering} = {speed} * {STEERING_KP} * ({line_position} + {lookahead})");

        const MAX: i32 = MAX_SPEED as i32;
        let left = (speed + steering).clamp(-MAX, MAX) as i16;
        let right = (speed - steering).clamp(-MAX, MAX) as i16;

        (left, right)
    }
}

// Returns once the path has been clear for `OBSTACLE_CLEAR_DURATION`.
async fn wait_for_obstacle_clear(range: &RangeSensor, range_filter: &mut RangeFilter) {
    let mut unblock_at: Option<Instant> = None;
    let mut ticker = Ticker::every(OBSTACLE_POLL);
    loop {
        ticker.next().await;

        range_filter.add(range.read());
        let dist = range_filter.filtered().distance_long();
        if dist > OBSTACLE_CLEAR_M {
            let now = Instant::now();
            if let Some(unblock_at) = unblock_at {
                if now >= unblock_at {
                    return;
                }
            } else {
                unblock_at = Some(now + OBSTACLE_CLEAR_DURATION);
            }
        } else if unblock_at.take().is_some() {
            log::info!("Obstacle returned at {dist:.2} m, resetting timer.");
        }
    }
}

/// Reads the line sensor and verifies that there is only one line detected
/// centered on the sensor.
async fn read_line_for_start(hal: &mut Hal<'_>) -> Option<LineDetection> {
    let detections = detect_line(&hal.line_sensor.read().await);

    detections
        .iter()
        .exactly_one()
        .ok()
        .filter(|d| d.position.abs() <= LINE_CENTERED_THRESHOLD)
        .cloned()
}

struct RangeFilter {
    measurements: [u16; 7],
    i: usize,
}

impl RangeFilter {
    fn new(first: RangeMeasurement) -> RangeFilter {
        RangeFilter {
            measurements: [first.raw; 7],
            i: 0,
        }
    }

    fn add(&mut self, measurement: RangeMeasurement) {
        self.measurements[self.i] = measurement.raw;
        self.i = (self.i + 1) % self.measurements.len();
    }

    fn filtered(&self) -> RangeMeasurement {
        let mut copied = self.measurements;
        copied.sort_unstable();
        RangeMeasurement {
            raw: copied[copied.len() / 2],
        }
    }
}

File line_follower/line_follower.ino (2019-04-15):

void setup() {
    for (int pin = 7; pin <= 11; ++pin)
    {
        pinMode(pin, OUTPUT);
        digitalWrite(pin, HIGH);
    }
}

void loop() {
    for (int pin = 7; pin <= 11; ++pin)
    {
        digitalWrite(pin, LOW);
        delay(100);
        digitalWrite(pin, HIGH);
    }
    delay(100);
    for (int pin = 10; pin >= 7; --pin)
    {
        digitalWrite(pin, LOW);
        delay(100);
        digitalWrite(pin, HIGH);
    }
    Serial.println("Beep");
    delay(1000);
}

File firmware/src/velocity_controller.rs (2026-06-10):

use embassy_time::{Duration, TICK_HZ};
use fixed::types::{I20F12, I52F12};
use lf_hal_types::motors::{MAX_SPEED, PwmT};

/// Fixed-point control gain. The 12 fractional bits match the scale used
/// throughout the controller arithmetic. Gains have no inherent range, so this
/// is an unbounded fixed-point type; sane values are enforced at construction.
pub type Gain = I20F12;

#[derive(Clone, Copy, Debug)]
pub struct Gains {
    kp: Gain,
    ki: Gain,
    kd: Gain,
    stiction_pwm: i32,
}

impl Gains {
    /// Constructor, all three arguments must be between 0 and 8
    #[must_use]
    pub fn new(kp: f32, ki: f32, kd: f32) -> Option<Self> {
        let in_range = |g: f32| (0.0..=8.0).contains(&g);
        if !in_range(kp) || !in_range(ki) || !in_range(kd) {
            return None;
        }

        Some(Self {
            kp: Gain::from_num(kp),
            ki: Gain::from_num(ki),
            kd: Gain::from_num(kd),
            stiction_pwm: 0,
        })
    }

    /// Constructor from standard form PID controller parametrization
    /// <https://en.wikipedia.org/wiki/PID_controller#Standard_form>
    /// - `kp` must be between 0 and 8.
    /// - `ti` is the integral time constant in seconds
    ///   (how long the controller tolerates an error).
    ///   `kp / ti` must be between 0 and 8.
    /// - `td` is the derivative time constant in seconds
    ///   (how far forward in future does the controller look).
    ///   `kp * td` must be between 0 and 8.
    #[must_use]
    pub fn from_standard(kp: f32, ti: f32, td: f32) -> Option<Self> {
        Self::new(kp, kp / ti, kp * td)
    }

    /// Adds stiction PWM to the gains structure.
    /// This controls the minimum nonzero PWM output to be generated,
    /// helping to overcome stiction of the motors and gearboxes.
    #[must_use]
    pub fn with_stiction(mut self, pwm: PwmT) -> Self {
        self.stiction_pwm = pwm.get() as i32;
        self
    }
}

pub struct WheelUpdateResult {
    /// PWM command to send to the motor
    pub motor_pwm: PwmT,
    /// How many ticks we drove since last call to update
    pub ticks_since_last_update: i16,
    /// Measured immediate velocity (`tick_since_last_update / dt`)
    pub velocity: i16,
}

/// PID regulator for controlling PWM command for a single motor.
pub struct WheelController {
    /// The integral of the error, premultiplied by the kI gain (i.e. the
    /// integral term's contribution to the PWM output).
    integral: Gain,
    /// Last value of encoder input, used for speed calculation
    last_ticks: i16,

    last_velocity: i32,
}

impl WheelController {
    #[must_use]
    pub fn new(initial_ticks: i16) -> Self {
        Self {
            integral: Gain::ZERO,
            last_ticks: initial_ticks,
            last_velocity: 0,
        }
    }

    /// Updates the wheel velocity controller and returns the new PWM command
    /// - `dt` must be in the range (0ms, 120ms]
    /// - Velocity is limited by the measured motor maximum of +-15_000 ticks/s (= ~4.5m/s)
    /// - Acceleration is limited to 60_000 ticks/s^2 (= ~18m/s^2)
    pub fn update(
        &mut self,
        gains: &Gains,
        current_ticks: i16,
        setpoint: i16,
        dt: Duration,
    ) -> WheelUpdateResult {
        debug_assert!(dt > Duration::from_ticks(0) && dt <= Duration::from_millis(120));
        let dt_ticks = dt.as_ticks() as i32;

        let tick_delta = current_ticks.wrapping_sub(self.last_ticks) as i32;
        self.last_ticks = current_ticks;
        debug_assert!(tick_delta.abs() <= 1800);

        let velocity = tick_delta * TICK_HZ as i32 / dt_ticks;
        debug_assert!(
            velocity.abs() <= MAX_SPEED as i32,
            "Input range requirement"
        );

        let error = setpoint as i32 - velocity;
        debug_assert!(error.abs() < 48_000);

        let integral_update: Gain =
            (I52F12::from_num(gains.ki) * i64::from(error) * i64::from(dt_ticks) / TICK_HZ as i64)
                .to_num::<Gain>();
        self.integral += integral_update;

        let velocity_change = velocity - self.last_velocity;
        self.last_velocity = velocity;
        let acceleration = (velocity_change as i64 * TICK_HZ as i64 / dt_ticks as i64) as i32;
        debug_assert!(acceleration.abs() < 60_000, "Input range requirement");

        let stiction_ff = if setpoint > 0 {
            gains.stiction_pwm
        } else if setpoint < 0 {
            -gains.stiction_pwm
        } else if error > 0 {
            gains.stiction_pwm
        } else if error < 0 {
            -gains.stiction_pwm
        } else {
            0
        };

        let raw = (gains.kp * error).to_num::<i32>() + self.integral.to_num::<i32>()
            - (gains.kd * acceleration).to_num::<i32>()
            + stiction_ff;

        let clamped = raw.clamp(PwmT::MIN.get() as i32, PwmT::MAX.get() as i32);
        let clamping_error = raw - clamped;

        if clamping_error.signum() == integral_update.signum().to_num::<i32>() {
            // Undo the integral update if adding it to the raw output made it worse.
            // clamping_error == 0 && integral_update == 0: this is a no-op
            self.integral -= integral_update;
        }

        let motor_pwm = if clamped.abs() > gains.stiction_pwm {
            PwmT::new(clamped as i16).unwrap()
        } else {
            PwmT::new_static::<0>()
        };

        WheelUpdateResult {
            motor_pwm,
            ticks_since_last_update: tick_delta as i16,
            velocity: velocity as i16,
        }
    }

    /// Resets all internal state of the controller to zero, sets last ticks to given value.
    pub fn reset(&mut self, current_ticks: i16) {
        self.integral = Gain::ZERO;
        self.last_ticks = current_ticks;
        self.last_velocity = 0;
    }
}

/// Velocity controller for two wheels
pub struct VelocityController {
    gains: Gains,
    left: WheelController,
    right: WheelController,
}
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

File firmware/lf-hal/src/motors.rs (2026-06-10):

use esp_hal::{
    gpio::{AnyPin, Input, InputConfig, InputPin, Pull, interconnect::PeripheralOutput},
    mcpwm::{
        McPwm, PeripheralClockConfig,
        operator::{PwmActions, PwmPin, PwmPinConfig, PwmUpdateMethod, UpdateAction},
        timer::PwmWorkingMode,
    },
    pcnt::{
        Pcnt,
        channel::{CtrlMode, EdgeMode},
        unit::{Counter, Unit},
    },
    peripherals::{MCPWM0, PCNT},
    time::Rate,
};

pub use lf_hal_types::motors::PwmT;

pub struct MotorChannelPins {
    pub pwm_a: AnyPin<'static>,
    pub pwm_b: AnyPin<'static>,
    pub enc_a: AnyPin<'static>,
    pub enc_b: AnyPin<'static>,
}

const TARGET_PWM_FREQ: Rate = Rate::from_hz(25_000);

/// Glitch filter: maximum hardware value (10-bit register, ~6.4 µs at 160 MHz APB).
const PCNT_FILTER: u16 = 1023;

/// Generator action that holds the output unconditionally LOW.
/// Applied to the inactive H-bridge leg while the other leg is
/// PWM-controlled, and to both legs when braking.
const FORCE_LOW_A: PwmActions<true> = PwmActions::empty()
    .on_up_counting_timer_equals_zero(UpdateAction::SetLow)
    .on_up_counting_timer_equals_timestamp(UpdateAction::SetLow);
/// Same as `FORCE_LOW_A`, but typed to work on the B channel
const FORCE_LOW_B: PwmActions<false> = PwmActions::empty()
    .on_up_counting_timer_equals_zero(UpdateAction::SetLow)
    .on_up_counting_timer_equals_timestamp(UpdateAction::SetLow);

pub struct Motors<'d> {
    left_a: PwmPin<'d, MCPWM0<'d>, 0, true>,
    left_b: PwmPin<'d, MCPWM0<'d>, 0, false>,
    right_a: PwmPin<'d, MCPWM0<'d>, 1, true>,
    right_b: PwmPin<'d, MCPWM0<'d>, 1, false>,
    left_counter: Counter<'d, 0>,
    right_counter: Counter<'d, 1>,
    left_last: i16,
    right_last: i16,
}

impl<'d> Motors<'d> {
    #[must_use]
    pub fn new(
        mcpwm: MCPWM0<'d>,
        pcnt: PCNT<'d>,
        left: MotorChannelPins,
        right: MotorChannelPins,
    ) -> Self {
        let (left_a, left_b, right_a, right_b) =
            Self::init_pwm(mcpwm, left.pwm_a, left.pwm_b, right.pwm_a, right.pwm_b);

        let (left_counter, right_counter) =
            Self::init_encoders(pcnt, left.enc_a, left.enc_b, right.enc_a, right.enc_b);

        Self {
            left_a,
            left_b,
            right_a,
            right_b,
            left_counter,
            right_counter,
            left_last: 0,
            right_last: 0,
        }
    }

    /// Set PWM for both motors. Positive = forward, negative = backward, 0 = brake.
    pub fn set(&mut self, left: PwmT, right: PwmT) {
        apply_pwm(
            &mut self.left_a,
            &mut self.left_b,
            &mut self.left_last,
            left,
        );
        apply_pwm(
            &mut self.right_a,
            &mut self.right_b,
            &mut self.right_last,
            right,
        );
    }

    pub fn stop(&mut self) {
        self.set(PwmT::new_static::<0>(), PwmT::new_static::<0>());
    }

    #[must_use]
    pub fn encoders(&self) -> (i16, i16) {
        (self.left_counter.get(), self.right_counter.get())
    }

    fn init_pwm(
        mcpwm: MCPWM0<'d>,
        left_a: impl PeripheralOutput<'d>,
        left_b: impl PeripheralOutput<'d>,
        right_a: impl PeripheralOutput<'d>,
        right_b: impl PeripheralOutput<'d>,
    ) -> (
        PwmPin<'d, MCPWM0<'d>, 0, true>,
        PwmPin<'d, MCPWM0<'d>, 0, false>,
        PwmPin<'d, MCPWM0<'d>, 1, true>,
        PwmPin<'d, MCPWM0<'d>, 1, false>,
    ) {
        let clock_cfg = PeripheralClockConfig::with_prescaler(0);
        let mut mcpwm = McPwm::new(mcpwm, clock_cfg);

        mcpwm.operator0.set_timer(&mcpwm.timer0);
        mcpwm.operator1.set_timer(&mcpwm.timer0);

        let (la, lb) = mcpwm.operator0.with_pins(
            left_a,
            PwmPinConfig::new(FORCE_LOW_A, PwmUpdateMethod::SYNC_ON_ZERO),
            left_b,
            PwmPinConfig::new(FORCE_LOW_B, PwmUpdateMethod::SYNC_ON_ZERO),
        );
        let (ra, rb) = mcpwm.operator1.with_pins(
            right_a,
            PwmPinConfig::new(FORCE_LOW_A, PwmUpdateMethod::SYNC_ON_ZERO),
            right_b,
            PwmPinConfig::new(FORCE_LOW_B, PwmUpdateMethod::SYNC_ON_ZERO),
        );

        let timer_cfg = clock_cfg
            .timer_clock_with_frequency(
                PwmT::MAX.get() as u16,
                PwmWorkingMode::Increase,
                TARGET_PWM_FREQ,
            )
            .expect("PWM frequency unachievable");
        log::info!("PWM frequency is {}", timer_cfg.frequency());
        mcpwm.timer0.start(timer_cfg);

        (la, lb, ra, rb)
    }

    fn init_encoders(
        pcnt: PCNT<'d>,
        left_enc_a: impl InputPin + 'd,
        left_enc_b: impl InputPin + 'd,
        right_enc_a: impl InputPin + 'd,
        right_enc_b: impl InputPin + 'd,
    ) -> (Counter<'d, 0>, Counter<'d, 1>) {
        let pcnt = Pcnt::new(pcnt);
        let enc_cfg = InputConfig::default().with_pull(Pull::Up);

        setup_encoder(&pcnt.unit0, enc_cfg, left_enc_a, left_enc_b);
        let left_counter = pcnt.unit0.counter.clone();

        setup_encoder(&pcnt.unit1, enc_cfg, right_enc_a, right_enc_b);
        let right_counter = pcnt.unit1.counter.clone();

        // pcnt and its units drop here; GenericPeripheralGuards inside the
        // cloned Counters keep the PCNT peripheral clock enabled.
        (left_counter, right_counter)
    }
}

fn setup_encoder<'d, const N: usize>(
    unit: &Unit<'d, N>,
    cfg: InputConfig,
    enc_a: impl InputPin + 'd,
    enc_b: impl InputPin + 'd,
) {
    unit.set_filter(Some(PCNT_FILTER)).unwrap();

    let pin_a = Input::new(enc_a, cfg);
    let pin_b = Input::new(enc_b, cfg);
    let sig_a = pin_a.peripheral_input();
    let sig_b = pin_b.peripheral_input();

    unit.channel0.set_edge_signal(sig_a.clone());
    unit.channel0.set_ctrl_signal(sig_b.clone());
    unit.channel0
        .set_input_mode(EdgeMode::Decrement, EdgeMode::Increment);
    unit.channel0
        .set_ctrl_mode(CtrlMode::Keep, CtrlMode::Reverse);

    unit.channel1.set_edge_signal(sig_b);
    unit.channel1.set_ctrl_signal(sig_a);
    unit.channel1
        .set_input_mode(EdgeMode::Decrement, EdgeMode::Increment);
    unit.channel1
        .set_ctrl_mode(CtrlMode::Reverse, CtrlMode::Keep);

    unit.clear();
    unit.resume();
}
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

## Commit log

2016-04-03 Initial commit.
    3D sketch in solidworks and almost finished board.
    [XT60.SLDPRT, ball_caster.SLDPRT, ball_caster_3_8.SLDPRT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]
2016-04-16 Fixes before sending the board for fab.
    [board_simplified.SLDPRT, line_follower.brd, line_follower.sch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]
2016-05-12 Got rid of old versions of model.
    [board.SLDPRT, board_cutting.SLDASM, board_cutting.SLDDRW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]
2016-05-28 Testing arena design.
    [testing_map1.sldprt]
2016-05-29 Added missing connections to the board.
    [line_follower.brd]
2016-06-27 Updated the testing map to 1x1.5m format.
    [testing_map1.sldprt]
2016-06-29 Updated testing map
    [testing_map1.sldprt]
2016-07-03 One more change of the testing map.
    I should really be doing more useful stuff :-)
    [testing_map1.sldprt]
2017-02-13 More realistic wheel shape
    [pololu_40_mm_wheel.SLDPRT]
2017-02-13 3D printable distance sensor bracket, front ball and motor brackets.
    [board_simplified.SLDPRT, line_follower_simplified.SLDASM, sensor_bracket_3dp.SLDPRT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]
2017-02-13 Removed unused solidworks parts
    [ball_caster.SLDPRT, ball_caster_3_8.SLDPRT, sensor_bracket.SLDPRT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]
2018-12-16 Cleaned up old attempts
    [XT60.SLDPRT, battery.SLDPRT, board_simplified.DXF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]
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2019-05-18 Carrying case first draft
    [line_follower_box.SLDPRT]
2019-05-19 Fixed values of line sensor divider resistors.
    [line_follower.brd, line_follower.sch]
2019-05-19 Some work done on the carrying box.
    [line_follower_box.SLDPRT]
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2019-05-21 Prepared testing map for printing
    [testing_map.sldprt, testing_map1.sldprt]
2019-05-26 Carrying box ready for printing.
    [LF_box_clip_mid.STL, LF_box_clip_outer.STL, LF_box_lower.STL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]
2019-05-26 Cleaning up line sensor code, using at least a few parallel ADC reads.
2019-05-26 HAL is a singleton
    This avoids possibility of multiple HAL instances and also works around the issue with ADC initialization in contructor.
    [LfHal.cpp, LfHal.h, main.cpp]
2019-05-27 Fixing uninitialized ADC instance after move to singleton.
    [LfHal.cpp, LfHal.h]
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2019-06-01 Fixed changing motor directions (analogWrite and digitealWrite don't mix)
    [RobotHal.cpp]
2019-06-01 Fixing missing enum members in switch
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2020-04-25 Schematic for V2 mostly complete, time to work on the board.
    [line_follower.brd, line_follower.sch]
2020-04-26 Removed obsolete solidworks models
    [LF_box_clip_mid.STL, LF_box_clip_outer.STL, LF_box_lower.STL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]
2020-04-26 Updated gitignore
    [line_follower.brd, line_follower.sch]
2020-04-26 Rough layout of the new board
    [line_follower.brd]
2020-04-29 Decided to not use the encoder board on the motors, schematic tweaks and start of layout
    [line_follower.brd, line_follower.sch]
2020-05-19 Motor encoder boards are back, more layout work
    [line_follower.brd, line_follower.sch]
2020-05-20 Another quarter-afternoon of layout
    [line_follower.brd, line_follower.sch]
2020-05-22 Everything is connected on the board, but more work remains
    [line_follower.brd, line_follower.sch]
2020-05-22 Layout complete, now a day or two for it to sink in and find more errors.
    [line_follower.brd, line_follower.sch]
2020-06-04 started working on kicad version of the board
    [line_follower.sch]
2020-07-01 Board: Almost complete schematic, rough layout of pcb
    [line_follower.kicad_pcb, line_follower.sch]
2020-07-01 WIP mechanical design in F360
    [board-outline.dxf, lf.f3d, line-sensor-components.dxf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]
2020-07-23 Getting there with the PCB design.
    [line_follower.kicad_pcb, line_follower.sch]
2020-07-24 Updated sensor components position export
    [line-sensor-components.dxf]
2020-08-02 Board done except for the motor mounts
    [line_follower.kicad_pcb, line_follower.sch]
2020-08-02 Small PCB tweaks
    [line_follower.kicad_pcb, line_follower.sch]
2020-08-02 Placed motor mounting holes and silkscreen outlines.
    Board done for now.
    [battery-outline.dxf, lf.f3d, line_follower.kicad_pcb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]
2020-08-09 Untangled routing at the front of the robot a bit, moved battery location
    [battery-outline.dxf, line_follower.kicad_pcb, line_follower.sch]
2020-08-10 board: A bit more tweaking
    [line_follower.kicad_pcb, line_follower.sch]
2020-08-10 board: Moving silkscreen labels
    [line_follower.kicad_pcb]
2020-08-13 board: Manually fixed the outline to make step exporter happy
    [line_follower.kicad_pcb]
2020-08-14 pcb: tweaks, working step export
    [line_follower.kicad_pcb]
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2020-08-15 mechanical: WIP 3d printed parts and robot layout
    Front top and bottom pieces are ready, motor mounts and deck are missing
    [board.f3d, lf.f3d, lf.f3z]
2020-08-26 board: Added model for microswitch
    [line_follower.kicad_pcb]
2020-08-26 board: Some silkscreen change ...
    [line_follower.kicad_pcb]
2020-08-26 schematic: Fixing DRC warnings
    [line_follower.sch]
2020-08-26 schematic: Removed comment
    [line_follower.sch]
2020-08-26 board: Small tweaks + updating to match previous changes.
    [line_follower.kicad_pcb]
2020-08-26 board: Gerber files, sent for manufacture
    [line_follower-B_Cu.gbr, line_follower-B_Mask.gbr, line_follower-B_SilkS.gbr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]
2020-10-02 CAD model ready for 3D printing
    [board.f3d, deck.stl, front_bottom.stl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]
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2020-10-06 mechanical: Updated based experimental prints.
    [armor.dxf, battery-outline.dxf, board-outline.dxf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]
2020-10-14 schematic: Modified power supply LDO because of availability at Mouser.
    [line_follower.sch]
2020-10-14 mechanical: More updates, refreshed exports
    [armor.dxf, deck.stl, front_bottom.stl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]
2020-10-15 mechanical: Cleanup + added readme
    [armor.dxf, board-base-sketches.f3d, deck.stl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]
2020-11-12 schematic: Changed the 5V regulator again
    the previous one had wrong pinout
    [line_follower.kicad_pcb, line_follower.sch]
2020-11-12 mechanical: Printability improvements and smaller tweaks
    [armor.dxf, deck.stl, fdm-cut_washer.stl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]
2020-11-13 Renamed kicad exports directory
    [line_follower-B_Cu.gbr, line_follower-B_Mask.gbr, line_follower-B_SilkS.gbr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]
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2020-12-10 Removed the obsolete eagle project
    [line_follower.brd, line_follower.sch]
2020-12-10 Removed obsolete solidworks designs
    [line_follower_box.SLDPRT, sensor_bracket_3dp.SLDPRT, slider_3dp.SLDPRT]
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2020-12-12 Got rid of time types for now (will be replaced by std::chrono later)
    [FollowingLine.cpp]
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2020-12-20 Added missing code to set ADC attenuation
    [RobotHal.cpp]
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2020-12-27 HAL: Fixing I2C register reading code
    [Hal.cpp]
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2020-12-28 HAL/MPU6050: Fixed wrong register number
    [Mpu6050.cpp]
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2026-05-04 Fixed comments about ADC inversion
    [line_sensor.rs]
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2026-05-27 Fixing a line sensor bug
    This likely happened when an update of esp-hal fixed the inversion bug
    [line_sensor.rs]
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2026-06-05 Fixing button EMI issues in software only...
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2026-06-10 Moving line detection and velocity controlller to use `fixed`
    [hal_test.rs, main.rs, velocity_controller.rs]
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2026-06-13 Restructured main to use fixed 100Hz update rate, button checking in parallel withh line following
    [main.rs]
